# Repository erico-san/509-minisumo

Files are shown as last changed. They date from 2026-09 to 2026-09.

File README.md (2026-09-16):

# 509 Minisumo 

En este repositorio se encuentra toda la información de diseño de un Minisumo Bluetooth de 12x12cm. Este modelo destaca por tener un chasis fabricado completamente en PLA, una cuchilla frontal intercambiable y un sistema de amortiguación independiente para los motores basado en caucho de silicona. 

A 3 celdas cuenta con una velocidad maxima de 1 m/s, recomendable practicar a esta velocidad para dominar en el dojo.

Ensamble 3D de minisumo de PLA

## Archivos CAD

* **Ensamble general y piezas:** [Ver en Onshape](https://cad.onshape.com/documents/9d2ecc8a8a06794e88858b61/w/4d3c07dad9eb52e24bca0cad/e/eb328988e087dcca06bbb127)

Vista explosiva chasis minisumo PLA

## Componentes y Materiales

**Electrónica y Mecánica:**
* [Motorreductores verdes 48:1 Chihai CHF-T130](https://es.aliexpress.com/item/1005010205937236.html) (Se pueden reemplazar por los clásicos [motorreductores amarillos 48:1](https://es.aliexpress.com/item/1005004350962451.html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)).
* [Batería Gaoneng 3S 11.1V 300mAh](https://es.aliexpress.com/item/1005006010618131.html).
* [Tiras de plomo de 7mm para añadir peso](https://es.aliexpress.com/item/1005005885246156.html) (Opcional, manipular bajo su propio riesgo por tratarse de plomo).

**Tornillería:**
* [Tornillos M2x6](https://es.aliexpress.com/item/1005004177352184.html).
* [2 und M3x23 y 2 und M3x4](https://es.aliexpress.com/item/1005012581596315.html).

**Fabricación (Impresión 3D y Moldes):**
* **Caucho de silicona Shore A20** para las llantas y los amortiguadores. 
  * *Opción local (Lima, Perú):* [RTV Tipo 5 Plus (Silika Moldes)](https://silikamoldeseinsumos.pe/producto/caucho-de-silicona-rtv-tipo-5-plus-1kg/).
  * *Opción internacional:* [Aliexpress (No probada, dureza sin confirmar)](https://es.aliexpress.com/item/1005010538060521.html).
* [Filamento ePLA-HS eSUN de 1.75mm](https://digitalz3d.com/producto/filamento-3d-epla-hs-1-75mm-1kg-esun/). Se requieren aproximadamente 120gr para el chasis del minisumo y 50gr adicionales para los moldes. *Nota: Solo se necesita imprimir un molde de llantas para fabricar dos; el cilindro interno se debe recortar usando el espaciador impreso*.

## Detalles Técnicos

### Distribución de peso (Centro de Masa)

El robot tiene un peso total de 498 gr (rozando el límite reglamentario). Su diseño ubica el centro de masa por debajo del eje central de las ruedas. Esta configuración geométrica es crucial porque evita que el robot tienda a levantarse durante aceleraciones bruscas, manteniendo la rampa siempre con adherencia al tatami.

Analisis de centro de masa en robot minisumo

### Amortiguadores de silicona independientes

Los motores no están fijados rígidamente al chasis. Cada motor cuenta con un eje de giro propio y se apoya sobre una almohadilla de caucho de silicona (los moldes para fabricarlas están incluidos en el repositorio). 

Esto permite un desplazamiento angular interno independiente para cada motor. El propósito principal de este mecanismo es absorber las irregularidades del suelo o de las propias llantas, evitando que esas vibraciones mecánicas se transmitan al chasis y levanten la cuchilla frontal.

Diagrama de amortiguador de silicona para motores
Corte transversal amortiguador interno minisumo

## Control por Bluetooth y Firmware

El firmware para el ESP32 está incluido como código abierto dentro de este mismo repositorio, listo para ser descargado, compilado y modificado según tus necesidades:

* **Código fuente ESP32:** [`firmware/firmware.ino`](firmware/firmware.ino)

Para el control manual de este modelo (en base a la versión 505) se utiliza la aplicación **Bluetooth RC Car** para Android.

* **Descarga:** [Bluetooth RC Car en Softonic](https://bluetooth-rc-car.softonic.com/android).
App Android Bluetooth RC Car para control de minisumo

## Electrónica (Main Board)

La placa PCB diseñada para este modelo integra los componentes necesarios para manejar alta potencia en un espacio reducido:

* **Microcontrolador:** [ESP32 WROOM](https://es.aliexpress.com/item/1005009235650481.html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).
* **Regulación de voltaje:** [Módulo DC-DC a 5V (Capacidad máxima de 3A)](https://es.aliexpress.com/item/1005005393995240.html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).
* **Drivers de motor:** Se utilizan circuitos integrados de medio puente H [**BTN7960**](https://es.aliexpress.com/item/1005008173352053.html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) para el control de dirección y potencia de los motores. *(Nota técnica: Estos componentes soportan voltajes de operación de hasta 27V y picos de corriente de hasta 43A, asegurando que los motores Chihai trabajen sin problemas térmicos ni bloqueos)*.

**Esquemático:**

Esquematico PCB Minisumo ESP32 y BTN7960

**Diseño de la Placa (Layout):**

Layout Top PCB Minisumo

Layout Bottom PCB Minisumo

## Videos Adjuntos

<table>
  <tr>
    <td align="center">
      <a href="https://youtube.com/shorts/eMg-vKGihfI">
        Video de prueba pesaje de minisumo
      </a>
      <br><b>Pesaje oficial</b>
    </td>
    <td align="center">
      <a href="https://youtube.com/shorts/Ilnm2QnsiVM">
        Video de combate minisumo en competencia
      </a>
      <br><b>Combate en competencia</b>
    </td>
  </tr>
</table>

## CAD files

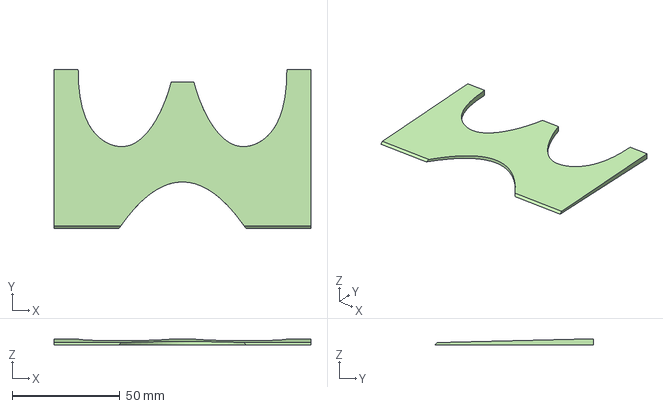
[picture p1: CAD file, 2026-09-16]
hardware/chasis/rampa (5).step
119.4 x 74.0 x 3.00 mm

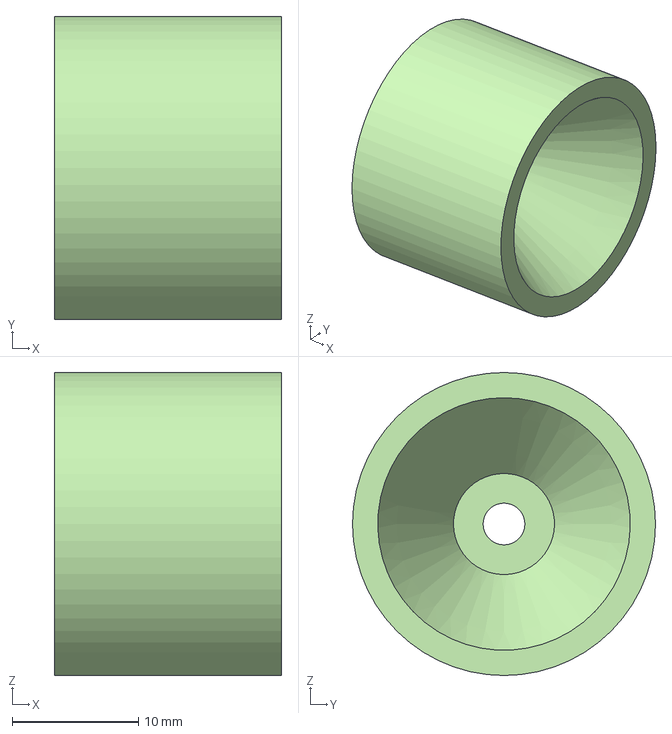
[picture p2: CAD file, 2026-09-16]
hardware/llantas/rim (2).step
18.0 x 24.0 x 24.0 mm

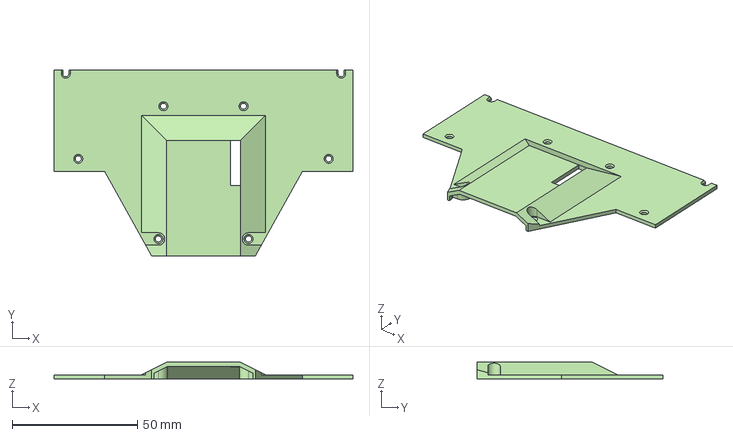
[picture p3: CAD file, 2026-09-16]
hardware/chasis/chasis up (4).step
119.4 x 74.3 x 6.60 mm

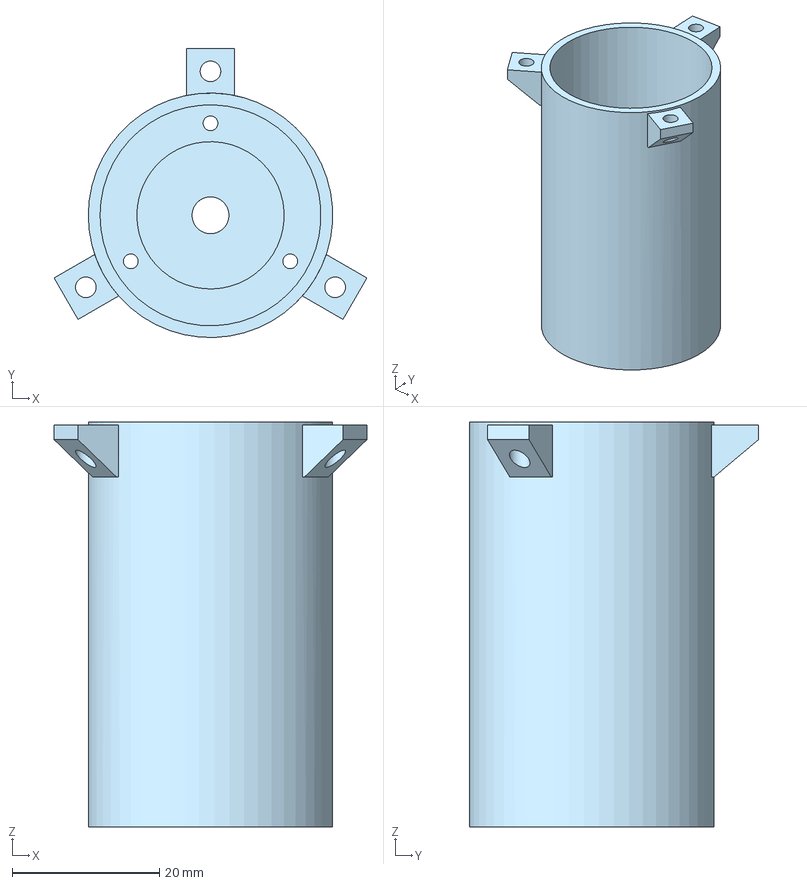
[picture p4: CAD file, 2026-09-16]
hardware/llantas/molde_llanta-d30 - base.step
42.5 x 39.2 x 55.0 mm

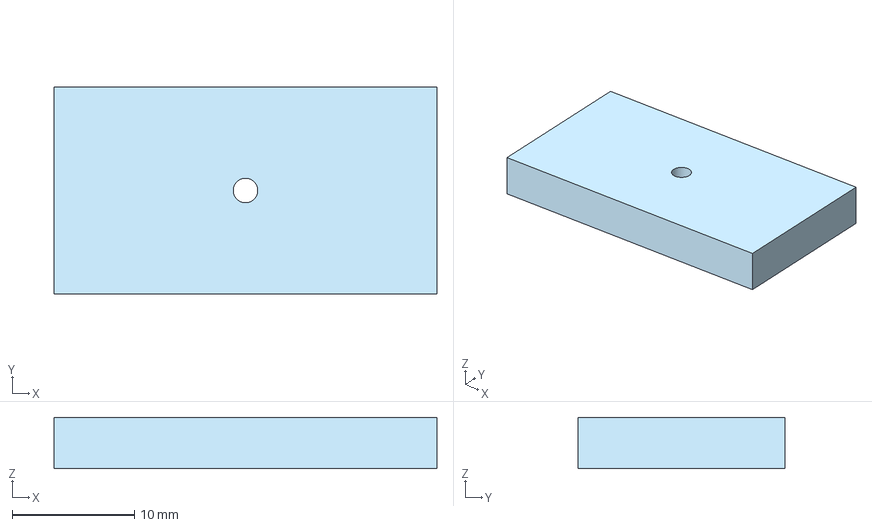
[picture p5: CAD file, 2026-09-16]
hardware/chasis/damper_molde - top.step
31.3 x 16.9 x 4.20 mm

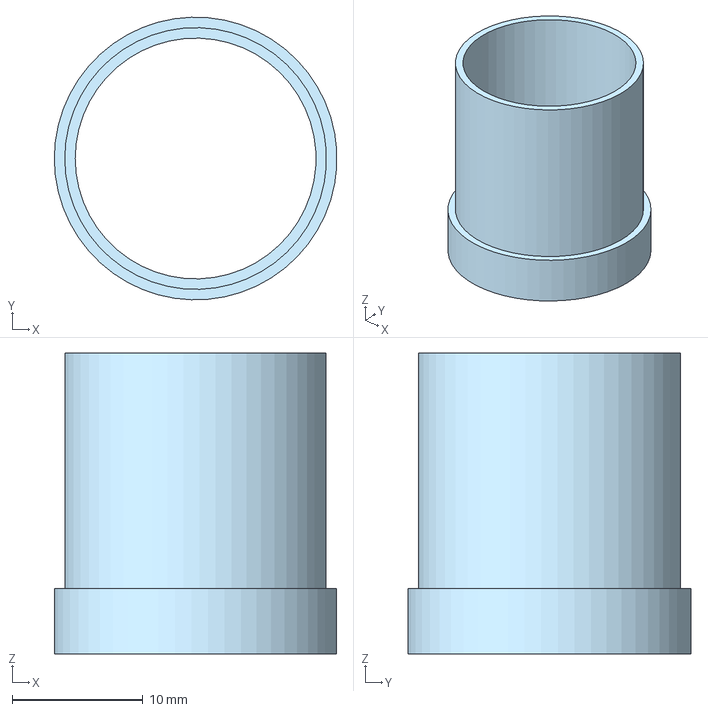
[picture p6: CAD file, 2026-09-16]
hardware/llantas/espaciador_corte_llanta.step
21.6 x 21.6 x 23.0 mm

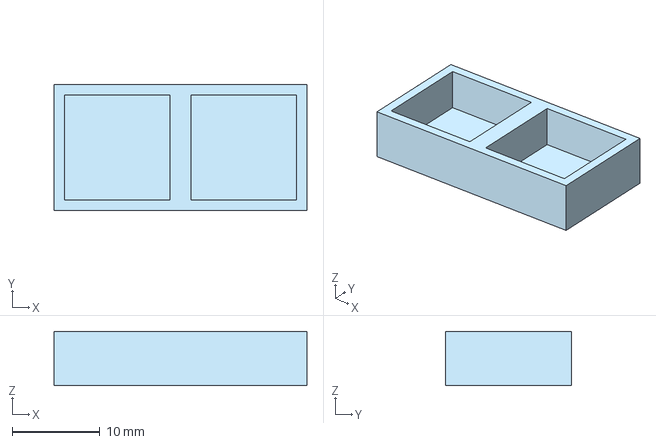
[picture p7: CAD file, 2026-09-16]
hardware/chasis/damper_molde - base.step
28.8 x 14.4 x 6.20 mm

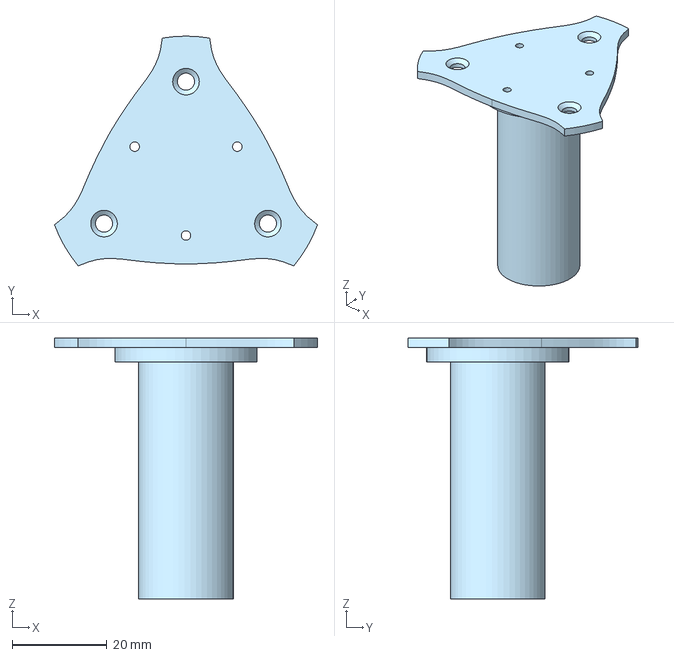
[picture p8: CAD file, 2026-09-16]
hardware/llantas/molde_llanta-d20 - top.step
55.4 x 48.4 x 55.0 mm

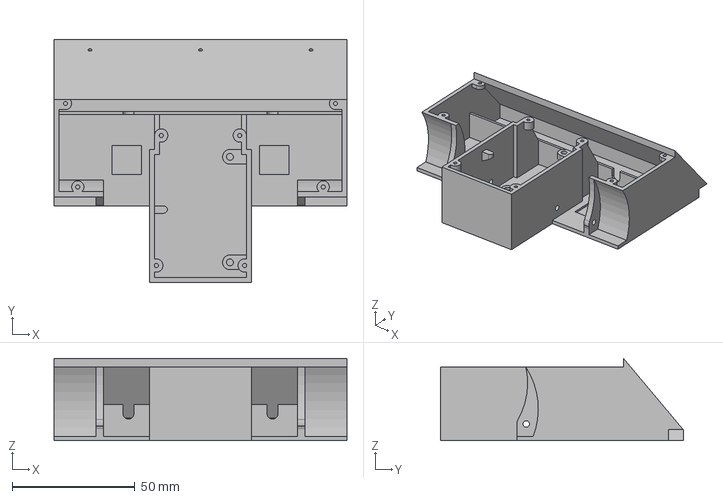
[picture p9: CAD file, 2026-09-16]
hardware/chasis/chasis (1).step
119.4 x 98.8 x 33.6 mm

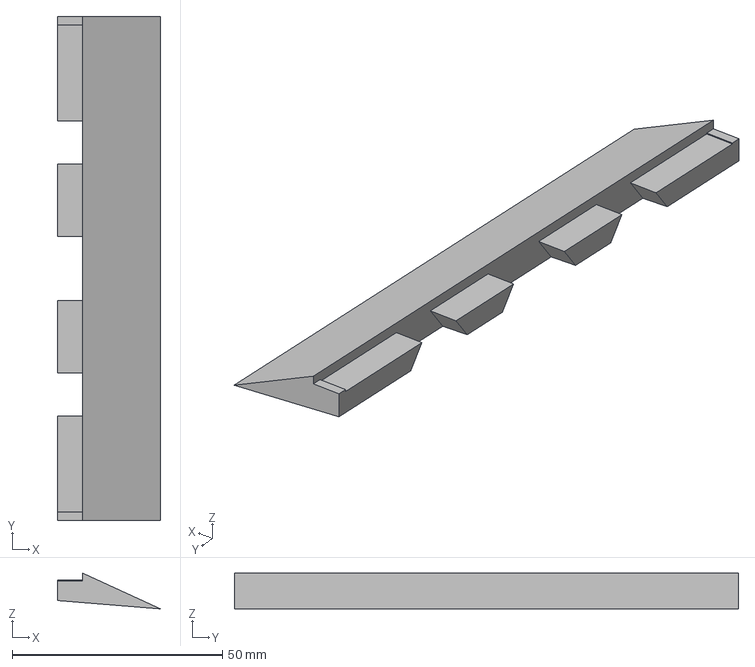
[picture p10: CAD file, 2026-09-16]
hardware/chasis/cuchilla (2).step
24.6 x 120.0 x 8.53 mm

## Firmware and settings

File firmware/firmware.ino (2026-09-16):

// es con ESP32 Devkit
#include "driver/mcpwm.h"
#include "BluetoothSerial.h"
String Nombre = "509";
BluetoothSerial BT;

// motores
#define a_black 18
#define a_red 5
#define b_red 16
#define b_black 19

unsigned char estado = 0;

//sobre 100, no sobre 255
int Speed = 30; 
int Speed_max = 100;
int diag = 20;

void setup(){
  BT.begin(Nombre); // mod para esp32

  // Configuración de pines de los motores como salidas
  config_motor();

  Serial.begin(9600);   // Configuramos el serial 
}

int cont=0;
void loop()
{
  estado = 0; // no guardar el último valor
  if (BT.available()) // mod para esp32
  {
    estado = BT.read(); // mod para esp32
    botonex();
  }
}

void botonex() // Función que procesa los comandos recibidos
{
  switch (estado){
   case 'F': // Adelante
    motor(Speed, Speed);
    break;

  case 'B': // Atrás
    motor(-Speed, -Speed);
    break;

  case 'L': // Izquierda
    motor(-Speed, Speed);
    break;

  case 'R': // Derecha
    motor(Speed, -Speed);
    break;

  case 'G': // Adelante izquierda 
    motor(Speed - diag, Speed + diag); //180
    break; 

  case 'I': // Adelante derecha 
    motor(Speed + diag, Speed - diag);
    break;

  case 'H': // Atrás izquierda 
    motor(-Speed + diag, -Speed - diag); //180
    break;    
 
  case 'J': // Atrás derecha }
    motor(-Speed - diag, -Speed + diag);
    break;
    
  case 'S': // Stop: Se activa frenado dinámico
    motor(0, 0);
    break;
    
  case '0':
    Speed = 0.1*Speed_max;
    break;
  case '1':
    Speed = 0.2*Speed_max;
    break;
  case '2':
    Speed = 0.3*Speed_max;
    break;
  case '3':
    Speed = 0.4*Speed_max;
    break;
  case '4':
    Speed = 0.5*Speed_max;
    break;
  case '5':
    Speed = 0.6*Speed_max;
    break;
  case '6':
    Speed = 0.7*Speed_max;
    break;
  case '7':
    Speed = 0.8*Speed_max;
    break;
  case '8':
    Speed = 0.9*Speed_max;
    break;
  case '9':
    Speed = 1.0*Speed_max;
    break;
  } 
}

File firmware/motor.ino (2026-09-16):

// Configuración de los pines y PWM para los motores
void config_motor(){
  // Configuración de los pines de los motores
  mcpwm_gpio_init(MCPWM_UNIT_0, MCPWM0A, a_red);  // Motor 1 - Canal A
  mcpwm_gpio_init(MCPWM_UNIT_0, MCPWM0B, a_black);  // Motor 1 - Canal B
  mcpwm_gpio_init(MCPWM_UNIT_1, MCPWM0A, b_red);  // Motor 2 - Canal A
  mcpwm_gpio_init(MCPWM_UNIT_1, MCPWM0B, b_black);  // Motor 2 - Canal B


  // Configuración del PWM
  mcpwm_config_t pwm_config;
  pwm_config.frequency = 1000;  // Frecuencia de 1kHz
  pwm_config.cmpr_a = 0;        // Ciclo de trabajo inicial canal A
  pwm_config.cmpr_b = 0;        // Ciclo de trabajo inicial canal B
  pwm_config.counter_mode = MCPWM_UP_COUNTER;
  pwm_config.duty_mode = MCPWM_DUTY_MODE_0;

  mcpwm_init(MCPWM_UNIT_0, MCPWM_TIMER_0, &pwm_config);  // Motor 1
  mcpwm_init(MCPWM_UNIT_1, MCPWM_TIMER_0, &pwm_config);  // Motor 2
}

void motor(int wa, int wb) {

  wa = constrain(wa, -99, 99);
  wb = constrain(wb, -99, 99);

  // Control Motor A
  if (wa > 0) {
    mcpwm_set_signal_low(MCPWM_UNIT_0, MCPWM_TIMER_0, MCPWM_OPR_B);  // IN2 bajo
    mcpwm_set_duty(MCPWM_UNIT_0, MCPWM_TIMER_0, MCPWM_OPR_A, wa);  // IN1 modulado
    mcpwm_set_duty_type(MCPWM_UNIT_0, MCPWM_TIMER_0, MCPWM_OPR_A, MCPWM_DUTY_MODE_0);
  } else if (wa < 0) {
    mcpwm_set_signal_low(MCPWM_UNIT_0, MCPWM_TIMER_0, MCPWM_OPR_A);  // IN1 bajo
    mcpwm_set_duty(MCPWM_UNIT_0, MCPWM_TIMER_0, MCPWM_OPR_B, -wa);  // IN2 modulado
    mcpwm_set_duty_type(MCPWM_UNIT_0, MCPWM_TIMER_0, MCPWM_OPR_B, MCPWM_DUTY_MODE_0);
  } else {
    mcpwm_set_signal_low(MCPWM_UNIT_0, MCPWM_TIMER_0, MCPWM_OPR_A);  // Mantener IN1 bajo
    mcpwm_set_signal_low(MCPWM_UNIT_0, MCPWM_TIMER_0, MCPWM_OPR_B);  // Mantener IN2 bajo
    mcpwm_set_duty(MCPWM_UNIT_0, MCPWM_TIMER_0, MCPWM_OPR_A, 0);
  }

  // Control Motor B
  if (wb > 0) {
    mcpwm_set_signal_low(MCPWM_UNIT_1, MCPWM_TIMER_0, MCPWM_OPR_B);  // IN2 bajo
    mcpwm_set_duty(MCPWM_UNIT_1, MCPWM_TIMER_0, MCPWM_OPR_A, wb);  // IN1 modulado
    mcpwm_set_duty_type(MCPWM_UNIT_1, MCPWM_TIMER_0, MCPWM_OPR_A, MCPWM_DUTY_MODE_0);
  } else if (wb < 0) {
    mcpwm_set_signal_low(MCPWM_UNIT_1, MCPWM_TIMER_0, MCPWM_OPR_A);  // IN1 bajo
    mcpwm_set_duty(MCPWM_UNIT_1, MCPWM_TIMER_0, MCPWM_OPR_B, -wb);  // IN2 modulado
    mcpwm_set_duty_type(MCPWM_UNIT_1, MCPWM_TIMER_0, MCPWM_OPR_B, MCPWM_DUTY_MODE_0);
  } else {
    mcpwm_set_signal_low(MCPWM_UNIT_1, MCPWM_TIMER_0, MCPWM_OPR_A);  // Mantener IN1 bajo
    mcpwm_set_signal_low(MCPWM_UNIT_1, MCPWM_TIMER_0, MCPWM_OPR_B);  // Mantener IN2 bajo
    mcpwm_set_duty(MCPWM_UNIT_1, MCPWM_TIMER_0, MCPWM_OPR_A, 0);
  }
}

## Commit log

2026-09-16 cambio de nombre a carpeta
2026-09-16 Update Bluetooth control and firmware section in README
    Added information about Bluetooth control and ESP32 firmware.
